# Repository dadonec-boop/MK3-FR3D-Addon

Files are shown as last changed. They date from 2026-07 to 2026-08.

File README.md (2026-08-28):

# MK3 + FR3D Addon

Public firmware for the **Desktop Filament Extruder MK3**, with **FR3D Addon** modifications by **Claudio Dadone**.

Based on **MACKEREL** (Marlin-derived filament extruder firmware by Filip Mulier / Hugh Lyman).

You can use this firmware in two ways:

1. **Standalone** — MK3S+ with FR3D Addon from the machine LCD (no Raspberry Pi gateway / web app required)
2. **Internet and/or LAN** — optional gateway + the same web app, over the internet or on local WiFi (with or without internet) ([fr3d-addon.web.app](http://fr3d-addon.web.app/))
   - **Raspberry Pi Zero 2 W** — compact totem; analog diameter sensor on MK3 pin **A3** (Hall / ARTME 3D optical)
   - **Raspberry Pi 3B** — full USB host; analog **A3** *or* **BDWidth** laser diameter sensor (USB on the Pi)
   - **Windows PC** — dedicated notebook/PC next to the extruder (`FR3DGateway.exe`)

---

## What this repository contains

| Content | Description |
|---|---|
| `MK3/` | Firmware sources (Arduino / Mega — flash this folder) |
| [`dist/MK3-FR3D-Addon.zip`](dist/MK3-FR3D-Addon.zip) | Ready-to-download ZIP of `MK3/` for Arduino IDE |
| [`docs/USER_GUIDE_...pdf`](docs/USER_GUIDE_FR3D_MK3_EN_ch1-2-3-4-5.pdf) | Standalone user guide (sensor, LCD, predictor operation) |
| [`docs/ayuda_fr3d_es_revision.docx`](docs/ayuda_fr3d_es_revision.docx) | Web app in-app help — Spanish review export (106 topics; live help at [fr3d-addon.web.app](https://fr3d-addon.web.app/)) |
| [`docs/diameter_sensor_infidel/`](docs/diameter_sensor_infidel/) | Printable Hall-effect (INFIDEL-style) diameter-sensor parts (STL) |
| [Pi Zero 2 W gateway image (Release)](https://github.com/dadonec-boop/MK3-FR3D-Addon/releases/tag/pi-gateway-v0.8) | Optional **Raspberry Pi Zero 2 W** factory image — analog A3, compact totem (binary only) |
| [Pi 3B gateway image (Release)](https://github.com/dadonec-boop/MK3-FR3D-Addon/releases/tag/pi-gateway-pi3b-v0.9) | Optional **Raspberry Pi 3B** factory image — analog A3 **or** BDWidth USB digital diameter (binary only) |
| [BDWidth sensor (PandaPi)](https://www.pandapi3d.com/product-page/bdwidth-sensor) | Optional contactless laser diameter sensor for use with **Pi 3B** gateway (USB-C to the Pi) |
| [Windows gateway (Release)](https://github.com/dadonec-boop/MK3-FR3D-Addon/releases/latest) | Optional Windows PC gateway package (`FR3DGateway-windows-x64.zip` — **exe binary only**) |
| Tag `v-mk3-original` | Stock MK3 (Mackerel base), **without** FR3D Addon |
| Tag `v-mk3-fr3d` / branch `main` | Latest **MK3 + FR3D Addon** |

This repository publishes **MK3 board firmware** (GPL-3.0) and, via **GitHub Releases**, **binary-only** gateway packages:

- Raspberry Pi Zero 2 W **factory SD image** (analog A3)
- Raspberry Pi 3B **factory SD image** (analog A3 or BDWidth USB)
- Windows **FR3DGateway.exe** package (dedicated PC/notebook next to the extruder)

**Gateway Python source, Pi program OTA source zips, and the web app source are not published** in this repository or its Releases.

---

## What FR3D Addon adds to the firmware

Compared with original MK3, this firmware includes:

- Diameter measurement — **Analog A3** (Hall / optical) with LCD **6-point** calibration (1.50…2.00 mm), or **Digital USB** (BDWidth via Pi 3B gateway)
- Diameter **predictor** with **Auto On / Off** (automatic E/T apply vs suggest-only); **Optimizar** sets P* by acting on E+T while puller stays in Auto
- Predictor parameter menus (basic + Advanced)
- Host serial temperature setpoint (`T` / `RTFP`) capped dynamically at **max(190 °C, predictor Tmax + 5)**, with heater safety headroom (see CHANGELOG)
- Compact USB host commands and CSV telemetry (on-demand `CSVQ`; internal fusion 2 s)
- Extended EEPROM layout for FR3D settings (current schema **V32**)

See [CHANGELOG.md](CHANGELOG.md) for the full list of changes versus original MK3.

---

## Standalone user guide

For MK3S+ with FR3D Addon operating from the machine LCD (**standalone** — without Raspberry Pi gateway / web app):

- [USER_GUIDE_FR3D_MK3_EN_ch1-2-3-4-5.pdf](docs/USER_GUIDE_FR3D_MK3_EN_ch1-2-3-4-5.pdf)
- [USER_GUIDE_FR3D_MK3_EN_ch1-2-3-4-5.docx](docs/USER_GUIDE_FR3D_MK3_EN_ch1-2-3-4-5.docx) (editable Word)

Covers project scope, Addon FR3D overview, diameter hardware (Hall-effect INFIDEL-style or ARTME 3D optical), **6-point** Analog A3 calibration on the LCD (1.50…2.00 mm), main-screen use, and recommended steps for automatic predictor operation.

Printable Hall parts: [`docs/diameter_sensor_infidel/`](docs/diameter_sensor_infidel/).

---

## Download ZIP (Arduino IDE)

If you only want to flash the board, download the ready-made package:

- **[MK3-FR3D-Addon.zip](dist/MK3-FR3D-Addon.zip)**

### Steps on your PC

1. Download [`dist/MK3-FR3D-Addon.zip`](dist/MK3-FR3D-Addon.zip).
2. Unzip it. You will get a folder named **`MK3`** (it must stay named `MK3`, matching `MK3.ino`).
3. Install **Arduino IDE** (or a compatible AVR Mega 2560 / RAMPS toolchain as used by MK3).
4. In Arduino IDE: **File → Open…** and open `MK3/MK3.ino`.
5. Select the correct **board** and **port**.
6. Click **Upload**.

After a first flash on an older EEPROM, the board may load hardcoded defaults (`Hardcoded Default Settings Loaded` on serial) or migrate known FR3D EEPROM versions to **V32** (a previous 3-point Hall calibration is reset; recapture six points).

### Alternative (from source tree)

Clone or browse this repository and open `MK3/MK3.ino` directly — same result as using the ZIP.

---

## Internet and/or LAN control (MK3s + FR3D Addon)

This is an **optional** path. Standalone LCD operation above does **not** require a Pi or the web app.

This firmware is **prepared** for remote and local control when used with the **MK3s + FR3D Addon** product stack:

- Choose **one** gateway host next to the MK3: **Pi Zero 2 W**, **Pi 3B**, or **Windows PC**
- The **same web app** runs over the **internet** or on the **local LAN / WiFi**, with or without an internet connection
- Operational reference: [http://fr3d-addon.web.app/](http://fr3d-addon.web.app/) (cloud) or `http://<Pi-IP>/` on the same WiFi (LAN)

The web app / host stack is an **additional product feature** and is **not** published here as open-source.

Prebuilt **SD images** for both Pi gateways are available under [Releases](https://github.com/dadonec-boop/MK3-FR3D-Addon/releases) (image files only).

### Which Raspberry Pi should I use?

| Gateway | Best for | Diameter sensor |
|---|---|---|
| **Pi Zero 2 W** | Smallest totem on the extruder | Analog **A3** only (Hall INFIDEL or ARTME 3D optical on the MK3) |
| **Pi 3B** | BDWidth digital diameter or analog A3 with full USB ports | Analog **A3** *or* **[BDWidth](https://www.pandapi3d.com/product-page/bdwidth-sensor)** laser sensor (USB-C on the Pi) |
| **Windows PC** | Reuse an existing PC | Analog **A3** (sensor wired to the MK3 Mega) |

**BDWidth** is an optical width/motion sensor (PandaPi). Purchase: [pandapi3d.com — bdwidth sensor](https://www.pandapi3d.com/product-page/bdwidth-sensor).  
It connects to a **Pi 3B USB port** (USB-C cable included). The Pi Zero 2 W has **no USB host** for an extra sensor — use Pi 3B for BDWidth.

On Pi 3B with both devices connected, **any two USB-A ports** work. The gateway identifies the MK3 serial link (250000 baud, saved in config) and auto-detects BDWidth (500000 baud, PandaPi `pandapi3dV` probe) — you do not assign a fixed physical port number.

---

## Download Raspberry Pi Zero 2 W gateway image

Recommended when you use an **analog diameter sensor on MK3 pin A3** and want the smallest gateway totem.

Download the factory image from the Release:

- **[fr3daddon-v0.8-small.img.zst](https://github.com/dadonec-boop/MK3-FR3D-Addon/releases/download/pi-gateway-v0.8/fr3daddon-v0.8-small.img.zst)**  
  Release notes: [pi-gateway-v0.8](https://github.com/dadonec-boop/MK3-FR3D-Addon/releases/tag/pi-gateway-v0.8)

**Wiring (summary):** micro SD, **+5 V 2 A** on **PWR_IN**, **USB OTG** data port → MK3S+ USB-B (printer port).

After first boot, update the gateway program with CONSOLE `PI UPDATE GATEWAY latest`. That does **not** replace the SD image.

### Flash with Raspberry Pi Imager

1. Download [Raspberry Pi Imager](https://www.raspberrypi.com/software/).
2. Insert a micro SD card (**32 GB** or larger recommended).
3. Open Imager → **Choose OS** → **Use custom** → select `fr3daddon-v0.8-small.img.zst`.
4. **Choose storage** → your SD card → **Write**.
5. Insert the SD into the Pi Zero 2 W and power on.

---

## Download Raspberry Pi 3B gateway image (+ BDWidth)

Recommended when you use the **[BDWidth](https://www.pandapi3d.com/product-page/bdwidth-sensor)** contactless laser diameter sensor, or when you want analog A3 with a full-size Pi and multiple USB ports.

Download the factory image from the Release:

- **[fr3daddon-pi3b-v0.9-small.img.zst](https://github.com/dadonec-boop/MK3-FR3D-Addon/releases/download/pi-gateway-pi3b-v0.9/fr3daddon-pi3b-v0.9-small.img.zst)**  
  Release notes: [pi-gateway-pi3b-v0.9](https://github.com/dadonec-boop/MK3-FR3D-Addon/releases/tag/pi-gateway-pi3b-v0.9)

**Wiring (summary):**

- micro SD + **+5 V** power (micro USB)
- **MK3S+ USB-B** → any Pi 3B **USB-A** port (FR3D serial link to the Mega)
- **BDWidth USB-C** → another Pi 3B **USB-A** port (digital diameter; gateway auto-detects the sensor)
- On the MK3 LCD set **Diameter Sensor → Source → Digital USB** when using BDWidth

After first boot, update the gateway program with CONSOLE `PI UPDATE GATEWAY latest`. That does **not** replace the SD image.

### Flash with Raspberry Pi Imager

Same steps as Pi Zero 2 W, but select `fr3daddon-pi3b-v0.9-small.img.zst` and boot on a **Raspberry Pi 3B**.

---

## First boot / factory defaults (Pi Zero 2 W and Pi 3B)

- WiFi hotspot: **SSID `addonfr3d`** / password **`addonfr3d`**
- On the MK3S+ LCD open **Control → gateway FR3D**. That screen shows the web app URL, WiFi SSID, the gateway **IP** (with online status), and the pairing **Token**:

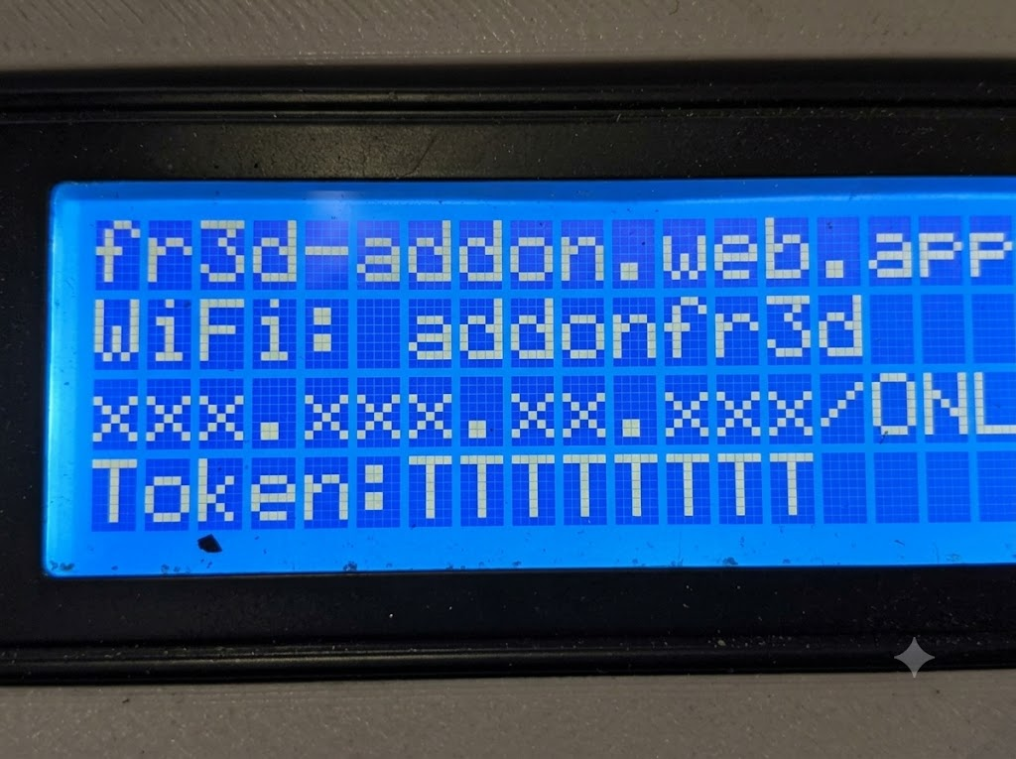
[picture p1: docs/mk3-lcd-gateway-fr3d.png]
MK3S+ LCD — gateway FR3D (IP and Token)
  

- Local setup page (from a device on the same WiFi / hotspot): **`http://<IP_from_LCD>:8080/`**  
  Use the IP shown on line 3 of the LCD (before `/ONL` or `/OFF`).  
  Login: **`addonfr3d` / `addonfr3d`**
- On first boot the image personalizes hostname / SSH keys automatically (no manual script needed).
- Then continue pairing from the web app ([fr3d-addon.web.app](http://fr3d-addon.web.app/)) using the **Token** from the same LCD screen.

---

## License

- **Firmware in this repository (`MK3/`):** [GPL-3.0](LICENSE)
  - Upstream Mackerel/Marlin base remains free software under the GNU GPL
  - FR3D Addon modifications are distributed under the same GPL-3.0 terms

- **Internet control stack (web app + gateway source):**  
  **not** included in this repository and **not** licensed here as public open-source software.

- **Pi Zero 2 W and Pi 3B factory images (Release assets):** distributed as binary images for end users; gateway source code is not published in this repository.

---

## Links

- Firmware ZIP (Arduino IDE): [dist/MK3-FR3D-Addon.zip](dist/MK3-FR3D-Addon.zip)
- Standalone user guide (PDF): [docs/USER_GUIDE_FR3D_MK3_EN_ch1-2-3-4-5.pdf](docs/USER_GUIDE_FR3D_MK3_EN_ch1-2-3-4-5.pdf)
- Pi Zero 2 W gateway image: [fr3daddon-v0.8-small.img.zst](https://github.com/dadonec-boop/MK3-FR3D-Addon/releases/download/pi-gateway-v0.8/fr3daddon-v0.8-small.img.zst)
- Pi 3B gateway image: [fr3daddon-pi3b-v0.9-small.img.zst](https://github.com/dadonec-boop/MK3-FR3D-Addon/releases/download/pi-gateway-pi3b-v0.9/fr3daddon-pi3b-v0.9-small.img.zst)
- BDWidth sensor (purchase): [pandapi3d.com — bdwidth](https://www.pandapi3d.com/product-page/bdwidth-sensor)
- Gateway program (Pi OTA + Windows): [latest Release](https://github.com/dadonec-boop/MK3-FR3D-Addon/releases/latest)
- System / web app reference: [http://fr3d-addon.web.app/](http://fr3d-addon.web.app/)
- Source: [github.com/dadonec-boop/MK3-FR3D-Addon](https://github.com/dadonec-boop/MK3-FR3D-Addon)

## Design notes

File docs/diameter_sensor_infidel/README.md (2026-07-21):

# Diameter sensor — Hall-effect (INFIDEL style) printed parts

## File

| File | Description |
|---|---|
| [`Hall_Sensor_Parts.stl`](Hall_Sensor_Parts.stl) | Single STL containing **all 9** printable bodies |

## How to print

1. Open `Hall_Sensor_Parts.stl` in your slicer (PrusaSlicer, Bambu Studio, Cura, Orca, etc.).
2. **Split into individual parts** (the file is a multi-body / multi-object mesh):
   - PrusaSlicer / Orca: right-click object → **Split** → **To objects** (or *To parts*).
   - Bambu Studio: right-click → **Split into objects**.
   - Cura: **Mesh Tools** → **Split model into parts** (plugin) or import and separate.
3. Arrange each piece on the bed and print (PLA/PETG as preferred for the head).
4. Assemble with roller, magnet, and SS495A linear Hall-effect sensor; mount on the MK3S+ filament path.

## Reference

- INFIDEL design (Printables): https://www.printables.com/model/57154-infidel-inline-filament-diameter-estimator-lowcost
- Standalone user guide: [`USER_GUIDE_FR3D_MK3_EN_ch1-2-3-4-5.pdf`](../USER_GUIDE_FR3D_MK3_EN_ch1-2-3-4-5.pdf)
- Web app help: [fr3d-addon.web.app](http://fr3d-addon.web.app/) → Hardware → Diameter Sensor Hardware

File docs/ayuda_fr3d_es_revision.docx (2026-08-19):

# FR3D — Ayuda in-app (español) para revisión

Instrucciones: edite solo Título, Resumen y Cuerpo. No cambie las líneas ID / Padre. Al terminar, en Google Docs: Archivo → Descargar → Microsoft Word (.docx) y envíelo. El recargo traducirá inglés y alemán a partir de este español.

Temas: 106. Idioma de este archivo: español solamente.

# FR3dAddon

ID: help.fr3d-addon [sección]

Título

FR3dAddon

Resumen (una línea)

FR3dAddon - Un producto de Formake3D compuesto de Firmware, Software y Hardware que extiende las funcionalidades del extrusor de filamento MK3S+ de ARTME3D.

Cuerpo

FR3dAddon permite, entre otras funciones, el control predictivo de diámetro del filamento y la optimización del rendimiento del flujo de material por minuto.

FR3dAddon incorpora la medición de diámetro. Ofrece tres posibilidades:
- Control de diámetro manual
- Control de diámetro analógico por el pin A3 de la placa MEGA del MK3S+
- Control de diámetro digital por puerto USB de la placa MEGA del MK3S+ a través del gateway de hardware FR3dAddon

=== Guía rápida — tres formas de operar ===

Elija un camino. Quien instala por primera vez suele mezclarlos.

> Nota de Arquitectura del Sistema:
> Cabe destacar que en la arquitectura de FR3dAddon, el firmware MK3S+FR3dAddon mantiene el control del lazo de realimentación (a través del sensor y el predictor), lo cual es fundamental para la estabilidad; mientras que el gateway (Pi o Windows) se encarga de la capa superior de monitoreo, análisis y comandos de alta complejidad. Esto evita que la latencia de LAN/Internet rompa el proceso crítico de control de extrusión.

1) Standalone — solo LCD de taller
Operación exclusiva en taller: Smart LCD y encoder del MK3S+. Sin gateway y sin app web.
- Descargar y aplicar el firmware MK3S+FR3dAddon desde GitHub FR3dAddon.
- Sensor analógico A3 o diámetro Manual (el Digital USB necesita gateway).
- Más: vea A) Standalone MK3S.

2) LAN — WiFi local, sin internet
La app web habla con el gateway (Raspberry Pi o PC Windows) en la misma WiFi del taller.
- El mismo firmware MK3 y UN gateway (imagen Pi o zip Windows).
- Pi: lea la IP en LCD Control -> AddonFR3D / Gateway FR3D (tercera línea) y abra http://xxx.xxx.xxx.xxx/
- Windows: ejecute FR3DGateway.exe en el PC junto a la máquina, misma WiFi.
- Más: vea B) Mk3s+Fr3dAddon ONLINE.

3) FULL Cloud — remoto por internet
Firebase + gateway junto a la máquina + https://fr3d-addon.web.app/
- El mismo gateway que LAN. Primera vez: cree usuario y contraseña, y asigne el token de 8 caracteres del LCD (misma pantalla, cuarta línea).
- Más: vea B) Mk3s+Fr3dAddon ONLINE.

Decisión
- ¿Solo LCD en la máquina? -> Standalone.
- ¿Misma WiFi, sin internet? -> LAN.
- ¿Control desde otro sitio o desde casa? -> FULL Cloud.

Si eligió LAN o FULL Cloud (Pi): Raspberry Pi Zero 2 W, microSD de 32 GB o más, grabe la imagen de fábrica, cable USB/OTG al MK3. WiFi primera vez: comparta internet del teléfono. SSID addonfr3d, contraseña addonfr3d. Después puede definir la WiFi del sitio.

Una vez dentro de la app podrá:
- Configuraciones en la pestaña Config
- Extruir filamento en Extrusor
- Bobinar filamento en Bobinador
- Analizar la traza de un filamento procesado en Análisis
- Ver y ejecutar comandos de control y estado en Consola
Más información de este modo: vea B) Mk3s+Fr3dAddon ONLINE.

Nota: descargas y GitHub - vea Recursos GitHub FR3dAddon.

Común a ambos modos: hardware del sensor de diámetro (vea Hardware - sensor).

Ver también (no editar): help.fr3d-addon.github, help.fr3d-addon.download, help.mk3, help.global, help.hardware, help.tips, help.tips.predictor-codes, help.global.help-panel

## Recursos GitHub FR3dAddon

ID: help.fr3d-addon.github Padre: help.fr3d-addon

Título

Recursos GitHub FR3dAddon

Resumen (una línea)

Descargas públicas: repo, zip MK3, PDF guía, STL, imagen Pi, gateway Windows.

Cuerpo

Acceda al repositorio GitHub FR3dAddon para:

Repositorio completo en GitHub:
https://github.com/dadonec-boop/MK3-FR3D-Addon

Paquete de firmware MK3 (instalar con Subir en Arduino IDE):
https://github.com/dadonec-boop/MK3-FR3D-Addon/raw/main/dist/MK3-FR3D-Addon.zip

Guía de usuario standalone (sensor, LCD, predictor) — PDF:
https://github.com/dadonec-boop/MK3-FR3D-Addon/raw/main/docs/USER_GUIDE_FR3D_MK3_EN_ch1-2-3-4-5.pdf

Piezas imprimibles sensor Hall (estilo INFIDEL) — carpeta STL:
https://github.com/dadonec-boop/MK3-FR3D-Addon/tree/main/docs/diameter_sensor_infidel
Archivo STL multi-cuerpo:
https://github.com/dadonec-boop/MK3-FR3D-Addon/raw/main/docs/diameter_sensor_infidel/Hall_Sensor_Parts.stl

Imagen de fábrica Raspberry Pi Zero 2 W (solo binario):
https://github.com/dadonec-boop/MK3-FR3D-Addon/releases/download/pi-gateway-v0.8/fr3daddon-v0.8-small.img.zst
Página del release: https://github.com/dadonec-boop/MK3-FR3D-Addon/releases/tag/pi-gateway-v0.8

Paquete gateway PC Windows — solo exe:
https://github.com/dadonec-boop/MK3-FR3D-Addon/releases/latest/download/FR3DGateway-windows-x64.zip
Todos los releases: https://github.com/dadonec-boop/MK3-FR3D-Addon/releases

Ver también (no editar): help.fr3d-addon.download, help.mk3.firmware, help.hardware, help.config.windows-gateway

## A) Standalone MK3S

ID: help.mk3 Padre: help.fr3d-addon [sección]

Título

A) Standalone MK3S

Resumen (una línea)

—

Cuerpo

A) Standalone MK3S - Opere el MK3S+ solo desde su Smart LCD: instale el firmware addon FR3D, lea el diámetro en la pantalla principal, configure menús AddonFR3D y calibre el sensor. No hace falta gateway ni app web para producir en local. Pros: más simple; offline; enfoque de taller. Contras: sin UI remota, roles en la nube ni análisis CSV web. Cableado del sensor en Hardware (común a A y B). Para control nube/web vea B) Mk3s+Fr3dAddon ONLINE.

Ver también (no editar): help.mk3.overview, help.mk3.firmware, help.hardware, help.global

### Cómo funciona standalone

ID: help.mk3.overview Padre: help.mk3

Título

Cómo funciona standalone

Resumen (una línea)

Producir solo desde el LCD del MK3: diámetro, menús AddonFR3D, sin internet.

Cuerpo

Cómo funciona standalone - Use solo el LCD y el encoder rotativo de la impresora. Vea diámetro en vivo (DXXXX/YYYY), modo predictor (A/M) y calibre el sensor desde Menú -> AddonFR3D / Control. No hace falta internet, Firebase ni login web para extruir.

Camino típico - Instale el firmware FR3D, cablee el sensor (Hardware) y produzca desde el LCD.

Después puede agregar un gateway y seguir usando el LCD a la vez; ese camino nube/colaborativo está en B) Mk3s+Fr3dAddon ONLINE (sin duplicar aquí). La calibración web (CONFIG) también vive en ONLINE.

Ver también (no editar): help.mk3.firmware, help.mk3.main-screen, help.mk3.hall-lcd-calibration, help.hardware, help.global

### Firmware MK3s+FR3D Addon GW

ID: help.mk3.firmware Padre: help.mk3

Título

Firmware MK3s+FR3D Addon GW

Resumen (una línea)

Cargar firmware FR3D en el MK3S+ para menús LCD, sensor Ø y gateway.

Cuerpo

Firmware MK3s+FR3D Addon GW - La placa principal de la impresora necesita el firmware addon FR3D para menús AddonFR3D en el LCD, sensor de diámetro y enlace USB al gateway (Pi o Windows).

Cómo instalarlo (montaje)
1) Conecte un PC Windows al USB-B del MK3S+ (cable de la impresora, no el del gateway).
2) Descargue el paquete MK3 y extráigalo en una carpeta vacía:
https://github.com/dadonec-boop/MK3-FR3D-Addon/raw/main/dist/MK3-FR3D-Addon.zip
3) Abra Arduino IDE y abra el proyecto de la subcarpeta MK3.
4) Elija placa Makerbase MKS Gen_L V2.1 y el puerto USB de la impresora (Herramientas -> Puerto).
5) Pulse Subir y espere a que termine (no desconecte el USB).

Luego reinicie la impresora si hace falta. Para control nube/LAN, conecte el Gateway FR3D Addon por USB. Solo taller: use los menús del LCD (standalone).

Ver también (no editar): help.config.hall.hardware, help.global.gateway, help.config.wifi.first-setup, help.mk3.overview

### Pantalla principal (display de diámetro)

ID: help.mk3.main-screen Padre: help.mk3

Título

Pantalla principal (display de diámetro)

Resumen (una línea)

DXXXX/YYYY en fila 2; A = predictor auto, M = manual.

Cuerpo

Pantalla principal - En el LCD home del MK3S+, la segunda fila muestra diámetro de filamento y modo predictor.

Campos de pantalla
1) DXXXX - Diámetro actual (XXXX = valor x 1000, ej. 1745 -> 1,745 mm)
2) /YYYY - Promedio de los últimos 10 s (20 muestras), ej. /1755 -> 1,755 mm
3) A o M - Modo predictor al final: A = ajuste automático, M = manual

Con Auto ON, el LCD puede mostrar tokens de estado junto a A (AH, AB, AS, AC, AO, AG, AN, AP, AU, AZ, AE±, AT±). Imprima la tabla de taller en Consejos y trucos → Códigos LCD del predictor. Los mismos códigos aparecen en el panel Flutter y en Ayuda → Extrusor → Asistente predictivo.

Use esta fila para verificar calibración del sensor de diámetro y compensación OFFSET sin abrir la app web.

Ver también (no editar): help.mk3.hall-lcd-calibration, help.extruder.live-status, help.tips.predictor-codes

### Calibración Diameter Sensor (menú MK3)

ID: help.mk3.hall-lcd-calibration Padre: help.mk3

Título

Calibración Diameter Sensor (menú MK3)

Resumen (una línea)

Source A3/USB/Manual, 6-pt 1.5-2.0, Need Calibrate! / CALIBRATE, OFFSET.

Cuerpo

Diameter Sensor en LCD MK3 - Menú -> Control -> AddonFR3D -> Diameter Sensor.

Source (exclusivo) - Analógico A3 (Hall/óptico en A3), Digital USB (BDWidth por el gateway) o Manual (editar D mm en LCD; el Ø no caduca). Solo una fuente activa. Firmware antiguo puede mostrar solo Analógico A3 (sin submenú Source); actualice el MK3 para USB/Manual.

Firmware actual - Línea 6-pt 1.5-2.0 (sin Pattern A/B). Capture seis patrones físicos: 1.50, 1.60, 1.70, 1.80, 1.90, 2.00 mm. Click guarda ADC. CALV=1 solo si los seis ADC son distintos y monótonos. Flashear este firmware borra una cal Hall de 3 puntos previa (EEPROM V32).

Firmware antiguo - Pattern Diameter muestra Now (p. ej. 1.7/1.75/2.0) y Set del otro preset (1.5/1.7/2.0 o 1.7/1.75/2.0). Cambiar patrón borra los 3 puntos y pone OFFSET (DOFF) en 0. La app web mantiene la UI A/B hasta reflashear el Mega.

Need Calibrate! - Solo si la calibración está incompleta (CALV=0). Click abre la lista Capture. Si ya está calibrado (CALV=1), el menú muestra CALIBRATE.

CALIBRATE - Capture cada mm etiquetado con el patrón físico correspondiente (Click guarda ADC).

OFFSET - Compensación fina de diámetro (DOFF). El predictor no actúa hasta CALV=1.
Mismos valores EEPROM que CONFIG -> Calibración sensor de diámetro (web).

Si Need Calibrate! no desaparece, el Ø queda congelado o el LCD muestra AC: vea Consejos → Calibración del sensor: solución de problemas (voltaje A3, limpiar Hall/óptico, comprobar que DXXXX se mueve).

Ver también (no editar): help.config.hall, help.config.hall.hardware, help.mk3.main-screen, help.tips.sensor-calibrate

## B) Mk3s+Fr3dAddon ONLINE LAN y/o INTERNET

ID: help.global Padre: help.fr3d-addon [sección]

Título

B) Mk3s+Fr3dAddon ONLINE LAN y/o INTERNET

Resumen (una línea)

—

Cuerpo

B) Mk3s+Fr3dAddon ONLINE - Operación en la red LAN y/o internet: app web Flutter + Firebase + host gateway (Raspberry Pi Zero 2 W o PC Windows).
Primera vez:
descargue UN paquete de gateway, flashee/ejecute, luego empareje el token del LCD. Esta rama cubre la UI web, software/hardware del gateway (Pi o Windows), pestañas y consola. Para producción solo LCD vea A) Standalone MK3S. Cableado del sensor en Hardware (común).

Ver también (no editar): help.fr3d-addon.download, help.fr3d-addon.cloud, help.global.tabs, help.mk3, help.hardware

### Resumen

ID: help.global.overview Padre: help.global

Título

Resumen

Resumen (una línea)

Control remoto del MK3S+ vía gateway FR3D en LAN o INTERNET.

Cuerpo

Resumen - Esta aplicación web controla un extrusor de filamento MK3S+ a través de un gateway FR3D en la nube (tótem Raspberry Pi Zero o un PC/notebook Windows dedicado junto a la máquina).
Comandos y telemetría viajan por Firebase Realtime Database.
Use la pestaña
EXTRUSOR para producción y predictor,
BOBINADOR para bobinado,
ANÁLISIS para logs CSV,
CONFIG para gateway y sensores,
CONSOLA (admin/super) para comandos en bruto.
Vea Cabecera de la app (zonas 1 y 2) para barra de estado y controles.

Ver también (no editar): help.fr3d-addon.download, help.global.header, help.global.gateway, help.global.tabs, help.config.windows-gateway

### Nube: descargar gateway (primera vez)

ID: help.fr3d-addon.download Padre: help.global

Título

Nube: descargar gateway (primera vez)

Resumen (una línea)

La nube necesita UN host: zip Windows O imagen Pi Zero 2 W. Enlaces aquí.

Cuerpo

Nube: descargar gateway (primera vez) - Si va a operar ONLINE, lo primero es un gateway junto al MK3. Elija UNA opción y descárguela.

No descargue ambos para una sola máquina. Elija PC Windows o Raspberry Pi Zero 2 W.

=== A) PC / notebook Windows (USB al MK3) ===
Archivo: FR3DGateway-windows-x64.zip
Descarga:
https://github.com/dadonec-boop/MK3-FR3D-Addon/releases/latest/download/FR3DGateway-windows-x64.zip
Todos los releases: https://github.com/dadonec-boop/MK3-FR3D-Addon/releases
Luego: descomprima, ejecute Iniciar_FR3DGateway.bat o FR3DGateway.exe, conecte USB, empareje el token en la app web.
Detalle: Gateway en PC Windows (CONFIG).

=== B) Raspberry Pi Zero 2 W (imagen SD de fábrica) ===
Archivo: fr3daddon-v0.8-small.img.zst (flashear a microSD)
Descarga:
https://github.com/dadonec-boop/MK3-FR3D-Addon/releases/download/pi-gateway-v0.8/fr3daddon-v0.8-small.img.zst
Página del release: https://github.com/dadonec-boop/MK3-FR3D-Addon/releases/tag/pi-gateway-v0.8
Luego: flashee la imagen, cablee alimentación/USB (vea Raspberry Pi GW hardware y software), únase al hotspot addonfr3d, dé internet a la Pi, empareje el token.

Cuando el gateway esté online - Abra https://fr3d-addon.web.app/ , inicie sesión e ingrese el token de 8 caracteres del LCD del MK3 (Control -> addonfr3d-gateway).

Updates posteriores - Pi: PI UPDATE en CONSOLA. Windows: WINDOWS UPDATE CHECK / HOWTO (no es una nueva imagen SD). Vea Actualizar gateway.

Ver también (no editar): help.fr3d-addon.cloud, help.fr3d-addon.modes, help.config.windows-gateway, help.config.wifi.first-setup, help.config.gateway.hardware, help.config.gateway.ota

### Hosts ONLINE: Pi vs Windows

ID: help.fr3d-addon.modes Padre: help.global

Título

Hosts ONLINE: Pi vs Windows

Resumen (una línea)

Misma app en la nube; elija tótem Pi Zero 2 W o gateway PC Windows.

Cuerpo

Hosts ONLINE: Pi vs Windows - Ambos usan la misma app web online. Elija el host gateway que convenga al taller.

1) Nube + Raspberry Pi Zero 2 W
Tótem compacto en la extrusora, USB/serial al MK3, internet por WiFi. PRIMERA DESCARGA: imagen SD de fábrica (Nube: descargar gateway).
Pros: siempre encendido; poco espacio; imagen con hotspot; control remoto; updates remotos; app de control local opcional en LAN (http://<IP-Pi>/) mientras Firebase sigue andando.
Contras: hardware Pi + imagen SD; WiFi del sitio; la UI en la nube depende de Firebase/internet (la UI LAN no).

2) Nube + gateway PC Windows
PC/notebook Windows dedicado junto a la extrusora con FR3DGateway.exe (USB COM).
PRIMERA DESCARGA: FR3DGateway-windows-x64.zip (Nube: descargar gateway).
Pros: aprovecha un PC habitual; COM fácil en CONFIG; updates por zip (WINDOWS UPDATE CHECK/HOWTO).
Contras: el PC debe quedar encendido y online; menos compacto; unzip manual; Firebase para la web.

Ver también (no editar): help.fr3d-addon.download, help.fr3d-addon.cloud, help.config.windows-gateway, help.config.gateway.hardware, help.config.wifi.first-setup, help.mk3

### Control Internet y/o LAN

ID: help.fr3d-addon.cloud Padre: help.global

Título

Control Internet y/o LAN

Resumen (una línea)

Misma app por internet o en LAN (WiFi), con o sin conexión a internet. Primero: descargar UN gateway.

Cuerpo

Control Internet y/o LAN - Además de usarla por internet, también puede operar la máquina en la red local (LAN) por WiFi, con o sin conexión a internet. Es la misma app: tanto en local como desde internet.

Para operar la máquina desde el navegador necesita:

1) La app web en https://fr3d-addon.web.app/ - inicie sesión, empareje con el token del LCD y use EXTRUSOR / BOBINADOR / ANÁLISIS / CONFIG / CONSOLA.
2) Un gateway junto al MK3 (elija uno):
- Raspberry Pi Zero 2 W con la imagen SD de fábrica, o
- un PC Windows con FR3DGateway (USB a la impresora).

PRIMERA VEZ - Descargue exactamente un gateway antes de emparejar:
- Windows: https://github.com/dadonec-boop/MK3-FR3D-Addon/releases/latest/download/FR3DGateway-windows-x64.zip
- Imagen Pi: https://github.com/dadonec-boop/MK3-FR3D-Addon/releases/download/pi-gateway-v0.8/fr3daddon-v0.8-small.img.zst
Vea también: Nube: descargar gateway (primera vez).

LAN en Pi - En la misma WiFi puede abrir http://<IP-Pi>/ (sin login), aunque no haya internet. Nube y LAN llegan a la misma Pi; use una sesión a la vez. Vea Ayuda -> Config -> App LAN y setup.

Ver también (no editar): help.fr3d-addon.download, help.fr3d-addon.modes, help.config.gateway.hardware, help.config.windows-gateway, help.global.tabs

### Emparejamiento del gateway

ID: help.global.gateway Padre: help.global

Título

Emparejamiento del gateway

Resumen (una línea)

Seleccione nombre y token del gateway para conectar esta sesión.

Cuerpo

Emparejamiento - Cada tótem físico (host Pi o PC Windows) tiene una clave de gateway y un token de 8 caracteres. Pulse el nombre o token en la barra de estado (zona 1) para abrir el selector y cambiar de tótem. Todos los comandos POLL3 y manuales van solo al gateway emparejado. Si el gateway o la nube Firebase están fuera de línea (punto de enlace rojo o gris), la app bloquea todos los comandos y deshabilita Extrusor, Bobinador, Predictor y Consola hasta que el gateway vuelva a estar en línea - así la UI no simula cambios que la máquina no recibió.

Ver también (no editar): help.global.user, help.global.header, help.global.connection, help.config.windows-gateway

### Usuario

ID: help.global.user Padre: help.global [sección]

Título

Usuario

Resumen (una línea)

—

Cuerpo

Inicio de sesión, roles y selección de tótem para operadores y superusuarios.

### Iniciar sesión (Operador)

ID: help.tips.operator-login Padre: help.global.user

Título

Iniciar sesión (Operador)

Resumen (una línea)

Correo y contraseña; el primer acceso pide el token del Gateway MK3S+.

Cuerpo

Iniciar sesión - Abra la app web e ingrese correo y contraseña. Si es su primera visita, pulse "Primera vez - crear cuenta", elija contraseña y regístrese. Use "Olvidé mi contraseña" si necesita un enlace por correo.

Primer emparejamiento - La primera vez que inicia sesión con una cuenta nueva (o sin tótem guardado), la app abre la pantalla de emparejamiento y pide el TOKEN mostrado en el MK3S+ en el menú Gateway. Este código de 8 caracteres lo asigna el Gateway FR3D Addon en la Raspberry Pi Zero 2 W conectada a la máquina. Escríbalo exactamente, opcionalmente un nombre amigable, y conecte. El tótem queda guardado en su cuenta.

Perfil operador - Tras iniciar sesión y emparejar puede usar EXTRUSOR, BOBINADOR, ANÁLISIS, CONFIG y CONSOLA. En la consola solo hay botones rápidos (CONECTAR, DESCONECTAR, WIFI, WHOAREYOU): sin texto libre ni ayuda de consola. En las demás pestañas puede ejecutar comandos de producción, pero no SO ni PI a nivel de host. Guardar perfiles del predictor globalmente en Firebase es para superusuarios; los operadores pueden cargar perfiles y ajustar parámetros en la sesión actual.

Configuración inicial de la Pi - Para una Raspberry Pi Zero 2 W nueva (imagen de fábrica, hotspot addonfr3d, token del menú MK3S+) vea CONFIG -> WiFi -> Configuración inicial del gateway en Ayuda. En la misma LAN puede abrir http://<IP-Pi>/ (app de control, sin login).

Ver también (no editar): help.global.roles, help.tips.operator-totem, help.config.wifi.first-setup, help.config.setup-web

### Roles de usuario

ID: help.global.roles Padre: help.global.user

Título

Roles de usuario

Resumen (una línea)

Operadores vs superusuarios; algunas acciones están restringidas.

Cuerpo

Roles - Los operadores pueden usar controles de producción dentro de los límites de su perfil. Los superusuarios pueden acceder a la CONSOLA, guardar perfiles del predictor globalmente en Firebase y gestionar usuarios. Si un botón está deshabilitado, su rol o el estado de la máquina puede bloquear la acción (por ejemplo, extrusor en marcha bloquea inicio del bobinador).

Ver también (no editar): help.tips.operator-login, help.console

### Tótem Gateway (Operador)

ID: help.tips.operator-totem Padre: help.global.user

Título

Tótem Gateway (Operador)

Resumen (una línea)

Elija el tótem de la máquina en la barra de estado; token de 8 caracteres.

Cuerpo

Selección de tótem - Cada línea de extrusión tiene un gateway Raspberry Pi (tótem) identificado por un token de 8 caracteres. En la barra gris bajo la cabecera, pulse el nombre o token subrayado para abrir el selector de gateway.

Tótems guardados - Seleccione uno de la lista. Puede asignar un nombre amigable al emparejar un token nuevo para reconocerlo fácilmente en planta.

Entrada manual - Ingrese el token de 8 caracteres del menú Gateway del MK3S+ (Gateway FR3D Addon en Raspberry Pi Zero 2 W), opcionalmente un nombre, y conecte.

Cambio - Cambiar de tótem no cierra la sesión. Todos los comandos y el estado en vivo aplican solo al gateway emparejado actual. Confirme el punto verde antes de iniciar extrusión o bobinado. Si el gateway o la nube están fuera de línea (punto rojo o gris), los comandos se bloquean y los controles de máquina quedan deshabilitados hasta que la Pi vuelva a estar en línea.

Ver también (no editar): help.global.gateway, help.global.connection

### Cabecera de la app (zonas 1 y 2)

ID: help.global.header Padre: help.global [sección]

Título

Cabecera de la app (zonas 1 y 2)

Resumen (una línea)

Zona 1 = barra de estado; zona 2 = sesión y vista.

Cuerpo

Cabecera de la app - La parte superior de la pantalla tiene dos zonas operativas:

1 - Barra de estado (conexión)
Franja gris bajo la marca y las pestañas. Muestra el color del enlace, la etiqueta de máquina, el token de 8 caracteres, la cuenta regresiva del poll y actualizar. Use esta zona para ver si la Pi está en línea y para cambiar de tótem.

2 - Controles de sesión y vista
Botones arriba a la derecha: CERRAR SESIÃ"N, ACERCA DE, idioma (EN/ES/DE), Ayuda (?) y zoom (+/- %). Controlan la sesión del navegador y el diseño de la página; no arrancan la extrusión.

Expanda los subtemas abajo para el detalle de cada zona.

Ver también (no editar): help.global.connection, help.global.header-actions, help.global.tabs

### 1 - Barra de estado (conexión)

ID: help.global.connection Padre: help.global.header

Título

1 - Barra de estado (conexión)

Resumen (una línea)

Color del enlace, etiqueta, token, cuenta regresiva del poll y actualizar.

Cuerpo

1 - Barra de estado (conexión)

Es la franja gris bajo EXTRUSOR / BOBINADOR / ANÁLISIS / CONFIG (zona 1 de la cabecera). De izquierda a derecha:
- Etiqueta de enlace en color - Estado combinado Firebase + gateway Pi + MK3 (por ejemplo verde MK3S conectado, naranja Gateway FUERA DE LÍNEA, gris problemas de nube).
- Etiqueta de máquina (p. ej. IZQ) - Subrayada; pulse para abrir el selector de gateway / tótem.
- Token (8 caracteres, p. ej. NWS7QRVY) - Subrayado; mismo selector que la etiqueta.
- Cuenta regresiva del poll - Barra segmentada / reloj hasta el próximo POLL2 automático.
- Icono actualizar - Sonda de inmediato y sale del standby.

Si esta zona dice Gateway FUERA DE LÍNEA, la Pi no responde. El standby reduce el poll; pulse actualizar cuando la Pi vuelva.

Ver también (no editar): help.global.header, help.global.polling, help.global.gateway

### Poll y standby

ID: help.global.polling Padre: help.global.connection

Título

Poll y standby

Resumen (una línea)

Telemetría automática cada 10-15 s; standby en reposo, frío u offline.

Cuerpo

Poll y standby - Durante el trabajo, la app consulta el gateway cada 10-15 segundos (más rápido con extrusión o bobinador activo). Si nada está en marcha, la temperatura real está bajo 100 degC y el objetivo no supera 150 degC (no hay preparación de corrida), entra en standby y consulta cada 30 minutos para ahorrar ancho de banda. Si el gateway Pi está offline (o cae el enlace Firebase) y no hay sesión de extrusión/bobinador, también entra en standby para no spamear polls fallidos. Cualquier pulsación o actualización manual reinicia la actividad y vuelve al poll normal. PAUSA del bobinador se trata como sesión activa y no debe entrar en standby.

Ver también (no editar): help.global.connection

### 2 - Controles de sesión y vista

ID: help.global.header-actions Padre: help.global.header

Título

2 - Controles de sesión y vista

Resumen (una línea)

Cerrar sesión, Acerca de, idioma, Ayuda y zoom.

Cuerpo

2 - Controles de sesión y vista

Arriba a la derecha de la cabecera blanca (zona 2), de izquierda a derecha:
- CERRAR SESIÃ"N - Termina el login Firebase en este navegador.
- ACERCA DE - Versión de la app, build id, créditos y QR al sitio del producto.
- Idioma (globo + EN/ES/DE) - Idioma de la UI y de este panel de ayuda.
- Ayuda (?) - Abre este árbol de ayuda (por defecto: FR3dAddon).
- Zoom - / % / + - Escala toda la UI por igual en ancho y alto (mantiene proporción). También Ctrl + rueda. Clic en el % para volver a 100%.

Estos controles nunca envían comandos EXTRUSOR ni BOBINADOR; solo afectan la sesión y el diseño.

Ver también (no editar): help.global.header, help.global.help-panel, help.global.tabs

### Pestañas

ID: help.global.tabs Padre: help.global [sección]

Título

Pestañas

Resumen (una línea)

EXTRUSOR, BOBINADOR, ANÁLISIS, CONFIG y CONSOLA (superusuario).

Cuerpo

EXTRUSOR - Extrusión en vivo, predictor, material, alertas de diámetro y gráficos.
BOBINADOR - Velocidad de bobinado, objetivo de metros, límites, inicio/parada/pausa y offset.
ANÁLISIS - Cargar logs CSV de materiales desde la Pi y revisar historial offline.
CONFIG - Detalles del gateway, calibración del sensor de diámetro y ajustes relacionados.
CONSOLA - Línea de comandos en bruto (solo superusuario).

Expande cada pestaña abajo para temas detallados.
Desde la app principal, use los chips Acceso directo a pestañas para ir a una pestaña.

Ver también (no editar): help.extruder, help.winder, help.analysis, help.config, help.console, help.hardware

### Extrusor

ID: help.extruder Padre: help.global.tabs [sección]

Título

Extrusor

Resumen (una línea)

—

Cuerpo

Extrusión en vivo en el MK3S+: inicio/parada, consignas, asistente predictivo, receta de material, monitoreo de diámetro y gráficos de telemetría.

Ver también (no editar): help.tips

### Controles

ID: help.extruder.controls Padre: help.extruder

Título

Controles

Resumen (una línea)

INICIAR/PARAR extrusor, modo pull, enfriamiento y precalentamiento.

Cuerpo

Controles -
INICIAR EXTRUSOR comienza la extrusión en el MK3;
PARAR EXTRUSOR termina la corrida.
PULL AUTO / PULL MANUAL alterna si el RPM de bobinado sigue la receta o consignas manuales.
COOLDOWN y PREHEAT envían presets térmicos rápidos.
Nota: Los controles se deshabilitan mientras el bobinador controla la máquina (RUN o PAUSA en la pestaña bobinador).

Ver también (no editar): help.extruder.setpoints, help.winder.controls

### Consignas (R / T / F / P)

ID: help.extruder.setpoints Padre: help.extruder

Título

Consignas (R / T / F / P)

Resumen (una línea)

Editar RPM sinfín, temperatura, ventilador y RPM pull.

Cuerpo

Consignas - Muestra real vs objetivo para velocidad sinfín (R), temperatura nozzle (T), ventilador (F) y RPM pull (P). Pulse EDITAR para cambiar objetivos, luego APLICAR para enviarlos al MK3. En modo PULL MANUAL el objetivo pull es editable; en PULL AUTO sigue la receta del material.

Ver también (no editar): help.extruder.material, help.extruder.controls

### Estado en vivo

ID: help.extruder.live-status Padre: help.extruder

Título

Estado en vivo

Resumen (una línea)

Líneas clave del último poll STATUS del gateway.

Cuerpo

Estado en vivo - Resume las líneas más importantes de la respuesta STATUS periódica: diámetro (D:), estado del extrusor e info de sesión. Se actualiza con la barra de poll en la franja de estado. Si está vacío, espere a que el enlace del gateway se ponga verde.

Ver también (no editar): help.global.connection, help.global.polling

### Asistente predictivo

ID: help.extruder.predictor Padre: help.extruder [sección]

Título

Asistente predictivo

Resumen (una línea)

Corrección manual o automática de diámetro (reglas R / T). Códigos LCD/Flutter.

Cuerpo

Códigos del predictor (LCD / Flutter)
SIN A / - - Auto OFF o predictor deshabilitado (PREDEN=0)
A - Auto ON, sin Δ E/T este ciclo
AH - Hold de transporte (espera metros/tiempo tras un correctivo)
AB - Diámetro en banda (cerca del objetivo → no corrige)
AS - Settling T (espera tras cambio de temperatura)
AC - Hall sin calibrar (CALV=0)
AO - Hall off (DH=0; FW actual fuerza DH=1)
AG - Aún no puede corregir: falta alguna condición de marcha (extrusor no en START/RUN, pull en MANUAL en vez de AUTO, o temperatura real lejos del objetivo |Tact−Ttgt|)
AN - Sin muestras de diámetro en la ventana
AP - Patinaje: aviso; actúa solo con Optimizar ON (|ΔE|≥2 rpm y P no sigue 90 s)
AU - No fusión: misma prueba E/P con T baja (actúa solo con Optimizar ON)
AZ - Freeze 90 s tras emergencia (no optimizar P)
AE+ / AE- - Aplicó corrección de E (sube / baja)
AT+ / AT- - Aplicó corrección de T (sube / baja)
Tabla imprimible de taller: Consejos y trucos → Códigos LCD del predictor.

Asistente predictivo - Muestra estado del predictor, correcciones sugeridas y reglas en vivo (ΔR / ΔT). Alterne Manual / automático en el interruptor del panel, o abra el icono de engranaje para parámetros PRED completos. El desplegable Perfil ofrece tres presets integrados (Conservador, Equilibrado, Agresivo) para recargar todos los límites como base; Equilibrado coincide con recomendaciones de producción. Active "Mostrar ayuda detallada" en ese diálogo para códigos, presets y campos.

Contrato
El predictor no mezcla Analog A3, Digital USB y Manual. Las tres fuentes llegan a un solo diámetro. Auto y Optimizar no saben de qué sensor vino.
Pulling debe estar en AUTO para que el predictor actúe. En pull MANUAL solo se muestra estado.

Diámetro
- Analog A3: promedio reciente del sensor Hall de la máquina.
- Digital USB: último valor del sensor USB. Si no llega dato durante 5 s, el predictor espera (no usa el Hall).
- Manual: el valor de calibre que usted carga. Queda válido aunque no lo cambie; no hace falta recargarlo cada 5 s.
Al cambiar de fuente se descarta lo anterior. A3 no usa USB/Manual. USB y Manual no usan el Hall.

Auto ON, Optimizar OFF (uso normal)
Si el diámetro está en banda (cerca del objetivo): no cambia RPM del sinfín ni temperatura.
Si está fuera de banda: corrige primero el sinfín y después la temperatura, y espera a que el material llegue al sensor.
Patinaje / no fusión: solo aviso en pantalla (AP / AU). No cambia consignas.

Auto ON, Optimizar ON
Úselo cuando el filamento ya sea dimensionalmente estable y desee buscar el punto óptimo de velocidad de tiraje y consumo energético sin comprometer la tolerancia de ±0,03 mm.
Igual que arriba para el diámetro. Además, si el diámetro lleva ~90 s cerca de banda, busca el objetivo de eficiencia P* (editable junto a Optimizar): P* es el tiraje (P) deseado mientras PULL sigue en Auto. El optimizador mueve sinfín (E/R) y temperatura (T) juntos para que el Auto suba o baje P. Nunca comanda P ni pasa a Manual. El Ø puede pasarse un poco de la banda muerta; si sale claro, vuelve la corrección normal de diámetro. Espere el hold de transporte entre pasos.
Detector de extremos (solo actúa con Optimizar ON): si el sinfín cambió 2 rpm o más (sube o baja) y el pulling no se movió, durante al menos 90 s: temperatura alta → patinaje (AP), baja un poco sinfín y/o temperatura; temperatura baja → no fusión (AU), sube temperatura. Luego pausa 90 s sin optimizar.

Firmware MK3 antiguo - Analog A3, extrusión, bobinado y predictor Auto siguen funcionando. Optimizar y P* aparecen solo si el QUERY del MK3 trae PREDOPT / PREDPSTAR. Digital USB y Manual aparecen solo si el QUERY trae DIAMSRC. Actualice el firmware del Mega para esas funciones extra.

Ver también (no editar): help.extruder.predictor.limits, help.extruder.diameter-alerts, help.config.hall, help.tips.use-predictor, help.tips.optimize-yield, help.tips.extreme-zones, help.tips.predictor-codes

### Editar límites del predictor (engranaje)

ID: help.extruder.predictor.limits Padre: help.extruder.predictor [sección]

Título

Editar límites del predictor (engranaje)

Resumen (una línea)

—

Cuerpo

Abra con el icono de engranaje en el panel del asistente predictivo. Edite parámetros PRED, elija modo Manual o Automático, seleccione preset Perfil (Conservador, Equilibrado o Agresivo) para recargar el paquete completo como punto de partida, y APLIQUE comandos PRED SET cambiados al MK3. Los superusuarios pueden Guardar perfiles globalmente en Firebase. Active "Mostrar ayuda detallada" en el diálogo: empieza con los códigos LCD/Flutter del predictor (SIN A, A, AH, AB, AS, AC, AO, AG, AN, AP, AU, AZ, AE±, AT±), luego ajustes recomendados, presets y campos.

Ver también (no editar): help.extruder.predictor.enabled, help.extruder.predictor.mode, help.extruder.predictor.target-d

### Activar asistente (Predictor ON/OFF)

ID: help.extruder.predictor.enabled Padre: help.extruder.predictor.limits

Título

Activar asistente (Predictor ON/OFF)

Resumen (una línea)

Interruptor maestro PREDEN. Recomendado: ON.

Cuerpo

Activar asistente - Interruptor maestro del predictor (PREDEN). En OFF no hay correcciones automáticas ni manuales aunque los límites estén cargados. En ON, el asistente evalúa error de diámetro cada ciclo CSV según Modo y compuertas de seguridad. Recomendado: ON.

### Modo (Manual / Automático)

ID: help.extruder.predictor.mode Padre: help.extruder.predictor.limits

Título

Modo (Manual / Automático)

Resumen (una línea)

Manual solo sugiere; Automático aplica correcciones.

Cuerpo

Modo - Manual calcula sugerencias Î"R/Î"T y las muestra sin enviar cambios al MK3. Automático aplica correcciones dentro de Emin/Emax, Tmin/Tmax y límites de paso. Recomendado: Manual al afinar material nuevo; cambie a Automático cuando el diámetro sea estable.

### Perfil

ID: help.extruder.predictor.profile Padre: help.extruder.predictor.limits [sección]

Título

Perfil

Resumen (una línea)

Recargar todos los campos del predictor desde un preset.

Cuerpo

Perfil - Desplegable en el diálogo de engranaje con cuatro opciones. Conservador, Equilibrado y Agresivo son tres presets integrados: seleccionar uno recarga cada límite numérico y ganancia en el formulario (forma rápida de reiniciar o cambiar estrategia). Personalizado significa edición local; no carga paquete hasta elegir de nuevo un preset con nombre. Modo, Activar asistente y CYCLE se conservan del borrador actual al cambiar presets. Pulse APLICAR para enviar solo valores PRED SET cambiados al MK3. Superusuarios pueden Guardar el paquete en Firebase (sobrescribe el preset integrado para ese nombre en todos los tótems). Punto de partida recomendado: Equilibrado.

Ver también (no editar): help.extruder.predictor.profile.conservative, help.extruder.predictor.profile.balanced, help.extruder.predictor.profile.aggressive

### Conservador (preset)

ID: help.extruder.predictor.profile.conservative Padre: help.extruder.predictor.profile

Título

Conservador (preset)

Resumen (una línea)

Correcciones suaves, banda RPM estrecha, deadband amplio.

Cuerpo

Conservador - Preset integrado para corridas estables con mínima intervención. Estos valores vienen cargados por defecto pero el usuario puede grabar a su preferencia cada perfil.

### Equilibrado (preset)

ID: help.extruder.predictor.profile.balanced Padre: help.extruder.predictor.profile

Título

Equilibrado (preset)

Resumen (una línea)

Valores recomendados de producción; punto de partida habitual.

Cuerpo

Equilibrado - Preset integrado alineado con ajustes de producción recomendados. Estos valores vienen cargados por defecto pero el usuario puede grabar a su preferencia cada perfil.

### Agresivo (preset)

ID: help.extruder.predictor.profile.aggressive Padre: help.extruder.predictor.profile

Título

Agresivo (preset)

Resumen (una línea)

Respuesta más rápida, deadband ajustado, pasos de corrección mayores.

Cuerpo

Agresivo - Preset integrado para corridas difíciles o deriva rápida de diámetro. Estos valores vienen cargados por defecto pero el usuario puede grabar a su preferencia cada perfil.

### DIAM debug CSV

ID: help.extruder.predictor.diam-debug Padre: help.extruder.predictor.limits

Título

DIAM debug CSV

Resumen (una línea)

Columnas diagnósticas extra en CSV MK3. Recomendado: ON.

Cuerpo

DIAMDEBUG - Añade columnas diagnósticas compactas al flujo CSV del MK3 (rechazos FIFO, estado debounce de mediana, mediana cruda vs publicada). Ãštil para verificar Salto mediana / Confirmación mediana. Recomendado: ON durante afinado y monitoreo.

### Objetivo D mm

ID: help.extruder.predictor.target-d Padre: help.extruder.predictor.limits

Título

Objetivo D mm

Resumen (una línea)

Diámetro nominal del filamento. Recomendado: 1,75 mm.

Cuerpo

Objetivo D mm - Diámetro nominal del filamento. Deadband, error y bandas de alerta se calculan respecto a este valor. Debe coincidir con la especificación de la bobina. Recomendado: 1,75 mm.

### Media banda D mm (Deadband/2)

ID: help.extruder.predictor.deadband Padre: help.extruder.predictor.limits

Título

Media banda D mm (Deadband/2)

Resumen (una línea)

Mitad del deadband alrededor de D objetivo. Recomendado: 0,03 mm.

Cuerpo

Media banda D mm - Mitad del deadband total (Deadband/2). Dentro de objetivo +/- banda el predictor no corrige. Banda más amplia = menos correcciones; más estrecha = más sensible. Recomendado: 0,03 mm.

### |Tact-Ttgt| máx degC (Coincidencia T)

ID: help.extruder.predictor.temp-match Padre: help.extruder.predictor.limits

Título

|Tact-Ttgt| máx degC (Coincidencia T)

Resumen (una línea)

Máx |real-objetivo| T para habilitar predictor. Recomendado: 2 degC.

Cuerpo

|Tact-Ttgt| máx - Si la temperatura real del nozzle difiere del objetivo RTF más que este valor, se inhibe la corrección predictiva hasta que T se estabilice. Evita correcciones durante calentamiento o transitorios grandes de T. Recomendado: 2 degC.

### Salto mediana mm (Med Salto)

ID: help.extruder.predictor.jump-debounce Padre: help.extruder.predictor.limits

Título

Salto mediana mm (Med Salto)

Resumen (una línea)

Umbral de salto grande de mediana (DIAMJDB). Recomendado: 0,15 mm.

Cuerpo

Salto mediana mm - La mediana móvil ~10 s debe cambiar al menos esta cantidad respecto a la última mediana publicada para tratarse como salto grande. Los saltos grandes quedan pendientes de confirmación en lugar de aplicarse de inmediato, filtrando picos y fallos del sensor. Recomendado: 0,15 mm.

### Confirmación mediana mm (Med conf)

ID: help.extruder.predictor.jump-confirm Padre: help.extruder.predictor.limits

Título

Confirmación mediana mm (Med conf)

Resumen (una línea)

Tolerancia de confirmación para salto pendiente (DIAMJPM). Recomendado: 0,06 mm.

Cuerpo

Confirmación mediana mm - Tras un salto grande pendiente, la mediana cruda de la siguiente ventana debe coincidir con el candidato dentro de +/- esta tolerancia antes de que el MK3 publique la nueva mediana. Recomendado: 0,06 mm.

### Emin (sinfín)

ID: help.extruder.predictor.e-min Padre: help.extruder.predictor.limits

Título

Emin (sinfín)

Resumen (una línea)

RPM mínimo del sinfín para correcciones. Recomendado: 9.

Cuerpo

Emin - Límite inferior de RPM que el asistente puede solicitar al corregir vía velocidad sinfín. Evita bloqueo o interrupción de flujo. Recomendado: 9 rpm.

### Emax (sinfín)

ID: help.extruder.predictor.e-max Padre: help.extruder.predictor.limits

Título

Emax (sinfín)

Resumen (una línea)

RPM máximo del sinfín para correcciones. Recomendado: 32.

Cuerpo

Emax - Límite superior de RPM para correcciones sinfín. Limita sobreaceleración y oscilación por saturación. Recomendado: 32 rpm.

### Tmin

ID: help.extruder.predictor.t-min Padre: help.extruder.predictor.limits

Título

Tmin

Resumen (una línea)

Límite térmico inferior del asistente. Recomendado: 174 degC.

Cuerpo

Tmin - Límite térmico inferior para correcciones de temperatura del predictor (no cambia por sí solo la consigna RTF base). Recomendado: 174 degC.

### Tmax

ID: help.extruder.predictor.t-max Padre: help.extruder.predictor.limits

Título

Tmax

Resumen (una línea)

Límite térmico superior del asistente. Recomendado: 189 degC.

Cuerpo

Tmax - Límite térmico superior para correcciones de temperatura del predictor. Mantiene el canal T en una ventana de proceso segura. Recomendado: 189 degC.

### CYCLE

ID: help.extruder.predictor.cycle Padre: help.extruder.predictor.limits

Título

CYCLE

Resumen (una línea)

Periodo de fusión fijo: 2 s (no configurable por operador).

Cuerpo

CYCLE - Periodo interno de fusión del predictor MK3, fijo en 2 segundos. El CSV por USB es on-demand (CSVQ); ya no es un ajuste 5/10 s. Tras cada fusión puede actuar, esperar T settle, o el hold de transporte (Hold transport m) por el recorrido boquilla->sensor.

### dR min (dE min)

ID: help.extruder.predictor.delta-e-min Padre: help.extruder.predictor.limits

Título

dR min (dE min)

Resumen (una línea)

Paso mínimo RPM por ciclo. Recomendado: 0,05.

Cuerpo

dE min - Corrección mínima de RPM sinfín por ciclo cuando actúa el canal R. Evita micro-pasos inefectivos. Recomendado: 0,05 rpm.

### dR max (dE max)

ID: help.extruder.predictor.delta-e-max Padre: help.extruder.predictor.limits

Título

dR max (dE max)

Resumen (una línea)

Paso máximo RPM por ciclo. Recomendado: 0,6.

Cuerpo

dE max - Cambio máximo de RPM sinfín por ciclo. Limita correcciones bruscas que podrían alterar el flujo. Recomendado: 0,6 rpm.

### kSpan R (kSpan E)

ID: help.extruder.predictor.kspan-e Padre: help.extruder.predictor.limits

Título

kSpan R (kSpan E)

Resumen (una línea)

Ganancia R por distancia a la banda. Recomendado: 10.

Cuerpo

kSpan E - Ganancia proporcional para correcciones sinfín según qué tan lejos está el diámetro fuera del deadband (componente span). Mayor = respuesta más fuerte fuera de banda. Recomendado: 10.

### kErr R (kErr E)

ID: help.extruder.predictor.kerr-e Padre: help.extruder.predictor.limits

Título

kErr R (kErr E)

Resumen (una línea)

Ganancia R por error de diámetro. Recomendado: 15.

Cuerpo

kErr E - Ganancia proporcional para correcciones sinfín según error absoluto de diámetro. Aumentar acelera respuesta R pero puede causar sobrepaso. Recomendado: 15.

### dT min degC

ID: help.extruder.predictor.delta-t-min Padre: help.extruder.predictor.limits

Título

dT min degC

Resumen (una línea)

Paso térmico base deseado por ciclo. Recomendado: 0,2 degC.

Cuerpo

dT min - Cambio de temperatura deseado/base por ciclo cuando el canal T está activo. Recomendado: 0,2 degC.

### dT max degC

ID: help.extruder.predictor.delta-t-max Padre: help.extruder.predictor.limits

Título

dT max degC

Resumen (una línea)

Tope de dT aplicado por ciclo. Recomendado: 1 degC.

Cuerpo

dT max - Tope duro de cambio de temperatura por corrección (dT aplicado = min(deseado, máx)). Mantener bajo por inercia térmica del nozzle. Recomendado: 1 degC.

### kSpan T

ID: help.extruder.predictor.kspan-t Padre: help.extruder.predictor.limits

Título

kSpan T

Resumen (una línea)

Ganancia T por distancia a la banda. Recomendado: 15.

Cuerpo

kSpan T - Ganancia térmica según distancia fuera del deadband (componente span del canal T). Recomendado: 15.

### kErr T

ID: help.extruder.predictor.kerr-t Padre: help.extruder.predictor.limits

Título

kErr T

Resumen (una línea)

Ganancia T por error de diámetro. Recomendado: 55.

Cuerpo

kErr T - Ganancia térmica según error absoluto de diámetro. Valores altos corrigen más rápido pero pueden causar caza térmica. Recomendado: 55.

### Margen R->T (Margen E)

ID: help.extruder.predictor.e-margin Padre: help.extruder.predictor.limits

Título

Margen R->T (Margen E)

Resumen (una línea)

Histéresis para pasar corrección R a T. Recomendado: 2 rpm.

Cuerpo

Margen E - Histéresis de RPM sinfín antes de que el predictor pueda pasar de correcciones R a T. Reduce alternancia entre canales. Recomendado: 2 rpm.

### Margen T->R (Margen T)

ID: help.extruder.predictor.t-margin Padre: help.extruder.predictor.limits

Título

Margen T->R (Margen T)

Resumen (una línea)

Histéresis para volver de corrección T a R. Recomendado: 2 degC.

Cuerpo

Margen T - Histéresis de temperatura antes de volver de correcciones T a R. Recomendado: 2 degC.

### Espera tras cambio T (Asentamiento T N)

ID: help.extruder.predictor.t-settle Padre: help.extruder.predictor.limits

Título

Espera tras cambio T (Asentamiento T N)

Resumen (una línea)

Fusiones tras corrección T. Rango: 15-20 (~30-40 s).

Cuerpo

Asentamiento T N - Tras un correctivo T, espera estas fusiones de 2 s antes de otra acción E/T (15 ~ 30 s ... 20 ~ 40 s; rango 15-20). Cubre inercia térmica del nozzle, no la distancia boquilla->sensor. Use Hold transport m para el recorrido del filamento hasta el sensor.

### Hold transporte m

ID: help.extruder.predictor.hold-m Padre: help.extruder.predictor.limits

Título

Hold transporte m

Resumen (una línea)

Metros de filamento a esperar tras E/T (boquilla->sensor). Recomendado: 0,50 m.

Cuerpo

Hold transporte m - Tras un correctivo E o T, espera hasta que la longitud extruida (L_m) avance esos metros, o hasta Hold timeout s. Ajústelo a la distancia física de salida de boquilla al sensor de diámetro. Muy bajo -> corrige antes de que el nuevo diámetro llegue al sensor; muy alto -> lento. Inicio recomendado: 0,50 m (ajuste a su máquina).

### Hold timeout s

ID: help.extruder.predictor.hold-timeout Padre: help.extruder.predictor.limits

Título

Hold timeout s

Resumen (una línea)

Espera máxima del hold de transporte. Recomendado: 60 s.

Cuerpo

Hold timeout s - Termina el hold de transporte si L_m se reinicia o el tiraje es demasiado lento para alcanzar Hold transport m. Evita que el predictor quede bloqueado. Recomendado: 60 s.

### Alertas de diámetro

ID: help.extruder.diameter-alerts Padre: help.extruder

Título

Alertas de diámetro

Resumen (una línea)

Avisos DLCD en la cabecera del predictor; pulse para recomendaciones.

Cuerpo

Alertas de diámetro - La insignia de color en la cabecera del asistente predictivo indica cuando el diámetro instantáneo (DLCD) está fuera de las bandas del predictor. Pulse para abrir recomendaciones de filamento fino o grueso. Para resolver paso a paso vea Consejos y trucos.

Ver también (no editar): help.tips.filament-thin, help.tips.filament-thick

### Material

ID: help.extruder.material Padre: help.extruder

Título

Material

Resumen (una línea)

Seleccione la receta y aplique R / T / F / P sugeridos.

Cuerpo

Material - Elija un material del catálogo del gateway. Los valores sugeridos de RPM sinfín, temperatura, ventilador y pull aparecen sobre el desplegable. APLICAR envía la receta al MK3. EDITAR abre el editor de material (nuevo, actualizar, eliminar colores y parámetros). ACTUALIZAR recarga la lista desde la Pi.

Nota: Niveles acumulados de masterbatch superiores al 5% pueden alterar la reología y viscosidad del polímero, requiriendo ajustes finos en las curvas de temperatura para evitar fragilidad en el filamento. Vea Consejos → Receta de mezcla y Homogeneizar el triturado.

Ver también (no editar): help.extruder.setpoints, help.tips.material-lots, help.tips.material-recipe, help.tips.two-pass-homogeneity, help.tips.grey-color-recipes

### Histograma

ID: help.extruder.histogram Padre: help.extruder

Título

Histograma

Resumen (una línea)

Gráfico de diámetro y RTF desde telemetría CSV en vivo.

Cuerpo

Histograma - Gráfica muestras recientes de telemetría: diámetro promedio (Davg) y opcionalmente E rpm, temperatura, ventilador y pull. GRABAR inicia el guardado del perfil CSV en la Pi; PARAR termina la grabación. LIMPIAR borra muestras locales sin afectar el log del gateway.

Ver también (no editar): help.analysis.histogram

### Bobinador

ID: help.winder Padre: help.global.tabs [sección]

Título

Bobinador

Resumen (una línea)

—

Cuerpo

Bobinado de filamento tras extrusión: velocidad, objetivo de metros, límites de diámetro, inicio/parada/pausa, calibración de offset y monitoreo de diámetro en vivo.

Ver también (no editar): help.extruder.controls

### Controles de bobinado

ID: help.winder.controls Padre: help.winder

Título

Controles de bobinado

Resumen (una línea)

INICIAR, PARAR, PAUSA/CONTINUAR y OFFSET.

Cuerpo

Controles de bobinado - INICIAR BOBINADO prepara el motor pull del MK3 e inicia la sesión. PARAR termina la sesión por completo. PAUSA baja el pull a 2 rpm (la sesión sigue activa); CONTINUAR restaura los 80 rpm estándar. OFFSET abre la calculadora de offset de diámetro (DLCD vs Dprom) para ajustar DOFF del sensor de diámetro. Los controles se deshabilitan mientras la pestaña extrusor controla la máquina sin bobinador.

Ver también (no editar): help.winder.parameters, help.winder.offset

### Parámetros

ID: help.winder.parameters Padre: help.winder

Título

Parámetros

Resumen (una línea)

RPM pull, objetivo de metros y ventana min/max de diámetro.

Cuerpo

Parámetros - RPM pull define velocidad de bobinado. El objetivo de metros es la meta de longitud del contador MK3. Diam min / max mm definen la ventana aceptable de diámetro promedio; cruzarla provoca pausa automática. EDITAR cambia valores localmente; APLICAR los envía al gateway. Metros acumulados muestra la longitud actual desde telemetría en vivo.

Ver también (no editar): help.winder.diameter-pause, help.winder.diameter-chart

### Gráfico de diámetro

ID: help.winder.diameter-chart Padre: help.winder

Título

Gráfico de diámetro

Resumen (una línea)

Histograma Davg en vivo con bandas de límite durante bobinado.

Cuerpo

Gráfico de diámetro - Gráfico móvil de diámetro promedio (Davg) desde telemetría CSV durante bobinado. Las líneas de referencia muestran la ventana min/max configurada y bandas de tolerancia. LIMPIAR reinicia muestras locales; el gateway sigue registrando mientras la sesión está activa.

Ver también (no editar): help.extruder.histogram

### Pausa por límite de diámetro

ID: help.winder.diameter-pause Padre: help.winder

Título

Pausa por límite de diámetro

Resumen (una línea)

Diálogo de pausa automática cuando Davg sale de la ventana min/max.

Cuerpo

Pausa por límite - Cuando el diámetro promedio sale de la ventana configurada durante el bobinado, el gateway pausa automáticamente y aparece este diálogo. Puede ajustar límites min/max, luego Continuar para enviar WINDER CONTINUE, o Parar para terminar la sesión. Vea Consejos y trucos para guía de filamento fino/grueso.

Ver también (no editar): help.tips.filament-thin, help.tips.filament-thick, help.winder.parameters

### Offset de diámetro (OFFSET)

ID: help.winder.offset Padre: help.winder

Título

Offset de diámetro (OFFSET)

Resumen (una línea)

Calcular y aplicar DOFF del sensor de diámetro desde DLCD vs Dprom.

Cuerpo

Offset de diámetro - Compara DLCD instantáneo con diámetro promedio móvil (Dprom) y propone un offset del sensor de diámetro (DOFF mm). Confirme para enviar HALL SET DOFF. Requiere MK3 conectado y lecturas válidas. También disponible en CONFIG -> Calibración del sensor de diámetro.

Ver también (no editar): help.config.hall

### Análisis

ID: help.analysis Padre: help.global.tabs [sección]

Título

Análisis

Resumen (una línea)

—

Cuerpo

Revisión offline de logs de producción guardados en la Pi (csv_logs). Explore historial de diámetro, navegue registros y encuentre eventos fuera de rango.

### Log de material (Pi csv_logs)

ID: help.analysis.material-log Padre: help.analysis

Título

Log de material (Pi csv_logs)

Resumen (una línea)

Staging siempre en G; al STOP se puede copiar al material elegido.

Cuerpo

Log de material - Las corridas en vivo siempre graban en csv_logs/G.csv (staging). Al STOP la app pregunta si copiar ese archivo sobre csv_logs/{seleccionado}.csv. Seleccione un material y cargue CSV FILE READ para perfiles guardados. ACTUALIZAR LISTA recarga materiales. Las cargas son solo lectura y no afectan la máquina en vivo.

Ver también (no editar): help.extruder.material

### Histograma

ID: help.analysis.histogram Padre: help.analysis

Título

Histograma

Resumen (una línea)

Gráfico de diámetro y tabla +/-5 registros alrededor de la fila seleccionada.

Cuerpo

Histograma - Grafica Davg (y trazas RTF opcionales) para la ventana visible alrededor del registro actual. Un marcador muestra el número de reg seleccionado. Debajo del gráfico, la tabla lista filas CSV +/-5 alrededor de la selección; pulse una fila para saltar. Las bandas de límite coinciden con umbrales de referencia del extrusor/bobinador.

Ver también (no editar): help.analysis.navigation

### VIEW y navegación de registros

ID: help.analysis.navigation Padre: help.analysis

Título

VIEW y navegación de registros

Resumen (una línea)

Span VIEW, botones paso, campo reg y filtro fuera de rango.

Cuerpo

VIEW y navegación - VIEW % define cuántas muestras son visibles alrededor del registro actual. Use < y > para un paso, << y >> para +/-10 filas. Escriba un número reg y Enter para saltar. Active filtro con umbrales Fino / Grueso: solo << y >> permanecen activos y saltan al siguiente registro con diámetro <= fino o >= grueso. Los mensajes indican "Filamento demasiado fino/grueso" o "No se encontraron registros fuera de rango".

Ver también (no editar): help.tips.filament-thin, help.tips.filament-thick

### Config

ID: help.config Padre: help.global.tabs [sección]

Título

Config

Resumen (una línea)

—

Cuerpo

Información de cuenta, detalles del gateway activo, WiFi y control LAN de la Raspberry Pi, opción de gateway en PC Windows, Raspberry Pi GW hardware y software, y calibración del sensor de diámetro MK3 (web). El cableado común del sensor está en Hardware (sensor).

### Cuenta

ID: help.config.account Padre: help.config

Título

Cuenta

Resumen (una línea)

Usuario conectado, rol, cerrar sesión y perfiles (superusuario).

Cuerpo

Cuenta - Muestra su correo, id de usuario Firebase y rol (Operador, Administrador o Superusuario). CERRAR SESIÓN termina la sesión. Los superusuarios ven PERFILES DE USUARIO para gestionar roles en Firebase. Los operadores usan solo EXTRUSOR, BOBINADOR, ANÁLISIS y CONFIG.

Ver también (no editar): help.global.roles, help.tips.operator-login

### Gateway activo

ID: help.config.gateway Padre: help.config

Título

Gateway activo

Resumen (una línea)

Estado online, token, hostname y cambiar gateway.

Cuerpo

Gateway activo - Muestra el tótem emparejado: online/offline, nombre amigable, token de 8 caracteres, clave gateway, hostname, MAC y serial cuando esté disponible. ACTUALIZAR actualiza desde Firebase. CAMBIAR GATEWAY abre el mismo selector que la barra de estado. Si el gateway o la nube están fuera de línea, los comandos de máquina se bloquean y Extrusor/Bobinador/Predictor/Consola quedan deshabilitados hasta que el gateway vuelva a estar en línea. El host puede ser Raspberry Pi Zero o un PC Windows dedicado (vea Gateway en PC Windows). Para primer emparejamiento vea Iniciar sesión (operador) en Consejos y trucos.

Ver también (no editar): help.global.gateway, help.tips.operator-totem, help.config.wifi.first-setup, help.config.windows-gateway

### Raspberry Pi GW (hardware y software)

ID: help.config.gateway.hardware Padre: help.config

Título

Raspberry Pi GW (hardware y software)

Resumen (una línea)

Tótem Pi Zero 2 W: imagen SD, cableado USB/alimentación, hotspot, conexión MK3S+.

Cuerpo

Raspberry Pi GW (hardware y software) - Tótem físico en el MK3S+ basado en Raspberry Pi Zero 2 W. Parte de B) Mk3s+Fr3dAddon ONLINE (no standalone). Flashee imagen de fábrica, cablee alimentación y USB, luego dé internet a la Pi vía hotspot addonfr3d.

Hardware
1) Raspberry Pi Zero 2 W
2) Cable micro USB a USB-A OTG (puerto USB datos Pi -> USB-A hembra para cable impresora)
3) Adaptador de alimentación micro USB +5 V 2 A (puerto PWR_IN Pi)
4) Micro SD 32 GB Clase 10
5) Cable USB-B a USB-A (puerto impresora MK3S+ -> adaptador OTG en la Pi)

Software
1) Descarga imagen de fábrica: https://github.com/dadonec-boop/MK3-FR3D-Addon/releases/download/pi-gateway-v0.8/fr3daddon-v0.8-small.img.zst (micro SD 32 GB Clase 10 o mayor)
2) Raspberry Pi Imager - Choose OS -> Use custom -> ese .img.zst -> Write

Conexiones
1) Conecte MK3S+ al Gateway FR3D Addon con cable USB-B a USB-A (USB-B impresora -> Pi vía adaptador OTG en puerto USB Pi, no PWR_IN).
2) Conecte la Pi a WiFi: SSID addonfr3d, contraseña addonfr3d (hotspot de fábrica; comparta internet del teléfono en primer arranque para registro en Firebase).

Tras cableado y flasheo, continúe con Configuración inicial del gateway para emparejamiento por token y login web. Alternativa PC Windows: Gateway en PC Windows (misma rama ONLINE).

Ver también (no editar): help.fr3d-addon.download, help.config.wifi.first-setup, help.config.setup-web, help.config.wifi, help.config.windows-gateway, help.config.hall.hardware, help.tips.operator-totem

### WiFi (Raspberry Pi)

ID: help.config.wifi Padre: help.config

Título

WiFi (Raspberry Pi)

Resumen (una línea)

Red conectada, agregar WiFi del sitio, perfiles guardados, conectar y eliminar.

Cuerpo

Panel WiFi - Gestione el WiFi del gateway Raspberry Pi Zero 2 W desde CONFIG.
WiFi conectado - Muestra el SSID activo (comando WIFI). ACTUALIZAR actualiza estado y lista guardada.
Nuevo WiFi - Ingrese SSID y contraseña, o pulse DISPONIBLES para escanear redes (WIFI AVAILABLE, ~30 s). ASIGNAR guarda el perfil (WIFI ADD), conecta (WIFI CONNECT) y verifica el enlace.
Redes guardadas - Perfiles en la Pi (WIFI LIST). CONECTAR cambia a una red guardada. ELIMINAR borra un perfil excepto el hotspot de fábrica addonfr3d, que no se puede quitar.
Red abierta - Use contraseña - al agregar una red sin clave.

Para el primer despliegue (imagen de fábrica, hotspot del teléfono, emparejamiento por token) vea Configuración inicial del gateway.

Ver también (no editar): help.config.setup-web, help.config.wifi.first-setup, help.config.gateway, help.tips.operator-login

### Gateway en PC Windows

ID: help.config.windows-gateway Padre: help.config

Título

Gateway en PC Windows

Resumen (una línea)

Ejecutar el gateway en un PC/notebook Windows sin Raspberry Pi Zero.

Cuerpo

Gateway en PC Windows - Alternativa al tótem Raspberry Pi Zero 2 W.

Cuándo usarlo - Un PC o notebook Windows dedicado junto a la extrusora, cable USB al MK3 e internet para Firebase. No hace falta hardware Pi, hotspot ni flashear SD.

Descarga - Desde Releases de MK3-FR3D-Addon (latest):
https://github.com/dadonec-boop/MK3-FR3D-Addon/releases/latest/download/FR3DGateway-windows-x64.zip
Descomprima en una carpeta y ejecute Iniciar_FR3DGateway.bat o FR3DGateway.exe.

Emparejamiento - Igual que en Pi: lea el token de 8 caracteres en el LCD del MK3 (Control -> addonfr3d-gateway / Windows), inicie sesión en https://fr3d-addon.web.app/ e ingrese el token. La presencia muestra hostType=windows.

CONFIG - Use Puerto COM (Windows) para listar/aplicar COMx. Los paneles WiFi / página LAN son solo Pi (ocultos o sin uso en Windows).

Actualizaciones - Administradores: en CONSOLA use WINDOWS UPDATE CHECK / HOWTO para el enlace. Cierre FR3DGateway, descomprima el paquete nuevo sobre la misma carpeta, conserve la configuración y vuelva a iniciar. Los comandos de update de Pi no aplican a Windows.

Ver también (no editar): help.config.serial-com, help.config.gateway.ota, help.config.wifi.first-setup, help.config.gateway, help.console.quick-commands

### Puerto COM (Windows)

ID: help.config.serial-com Padre: help.config

Título

Puerto COM (Windows)

Resumen (una línea)

Elegir y aplicar el puerto COM USB del MK3 cuando el gateway corre en Windows.

Cuerpo

Puerto COM (Windows) - Visible cuando el gateway emparejado es Windows.
SERIAL LIST - Actualizar lista COMx detectados y el puerto activo de config.
APLICAR COM - Envía SERIAL SET PORT y reconecta la sesión MK3 en ese puerto.
En Raspberry Pi este panel no se usa (USB by-id / UART se configuran en la Pi).
Vea también Gateway en PC Windows para instalación y actualización.

Ver también (no editar): help.config.windows-gateway, help.config.gateway, help.console

### App LAN y setup (Raspberry Pi)

ID: help.config.setup-web Padre: help.config

Título

App LAN y setup (Raspberry Pi)

Resumen (una línea)

Operar la máquina en la red local; WiFi en CONFIG; la nube sigue disponible.

Cuerpo

Operar en la red local (LAN) - Desde un celular, tablet o PC en la misma WiFi que la Raspberry Pi, abra la app de control en el navegador:
http://<IP-LAN-Pi>/
La app entra directo (sin login). Verá las mismas pantallas EXTRUSOR / BOBINADOR / CONFIG / CONSOLA que en la app en la nube, sin necesidad de Firebase.

WiFi - Cambie redes desde CONFIG -> WiFi en esa misma app (escanear, guardar, conectar).

Página de estado - Para ver la IP o MAC de la Pi:
http://<IP-LAN-Pi>:8080/ o http://<IP-LAN-Pi>/setup/

Internet / nube a la vez - Puede seguir usando https://fr3d-addon.web.app/ con emparejamiento por token del LCD. LAN y nube controlan la misma Pi; use una sesión a la vez para operar con claridad.

Cómo saber la IP de la Pi - Página de estado arriba, o CONFIG -> Gateway activo si la Pi está online, o en la lista de dispositivos del router. Tras unir la Pi a su WiFi suele verse una dirección 192.168.x.x.

Ver también (no editar): help.config.wifi, help.config.wifi.first-setup, help.config.gateway

### Configuración inicial del gateway

ID: help.config.wifi.first-setup Padre: help.config

Título

Configuración inicial del gateway

Resumen (una línea)

Flashear imagen Pi O zip Windows; emparejar token; login web.

Cuerpo

Dos opciones de host - Raspberry Pi Zero 2 W (tótem compacto) o un PC/notebook Windows dedicado junto a la extrusora (sin Pi). El emparejamiento Firebase y la UI web son los mismos.

Opción A - PC Windows - Vea Gateway en PC Windows: descargue FR3DGateway-windows-x64.zip, ejecute el exe (Firebase ya viene incluido), configure el COM en la web (CONFIG) y empareje con el token del LCD.

Opción B - Raspberry Pi (imagen de fábrica) - Descargue la imagen del gateway Pi Zero 2 W (solo binario):
https://github.com/dadonec-boop/MK3-FR3D-Addon/releases/download/pi-gateway-v0.8/fr3daddon-v0.8-small.img.zst
Página del release: https://github.com/dadonec-boop/MK3-FR3D-Addon/releases/tag/pi-gateway-v0.8
Flashee con Raspberry Pi Imager -> Use custom -> ese archivo .img.zst (SD de 32 GB o más).
La imagen incluye hotspot WiFi addonfr3d / addonfr3d para dar internet desde el teléfono y registrarse en Firebase.

Paso 1 (Pi) - Monte el hardware del gateway (ver FR3D Addon Gateway - hardware), flashee la imagen como arriba y conecte el MK3S+ a la Pi con cable USB-B a USB-A vía adaptador OTG.
Paso 2 - Encienda el gateway. En el teléfono (Pi), conéctese al WiFi addonfr3d (contraseña addonfr3d); en Windows use la red del PC como de costumbre.
Paso 3 - Espere hasta que el gateway se registre en el MK3S+. Lea el token de 8 caracteres: menú Control -> addonfr3d-gateway.
Paso 4 - Abra https://fr3d-addon.web.app/, cree cuenta (correo + contraseña) e inicie sesión.
Paso 5 - En el primer login la app pide el token del MK3S+. Escríbalo exactamente; la app verifica que el gateway esté catalogado en Firebase y lo vincula a su cuenta.
Paso 6 - Emparejamiento completo. Ya puede controlar la máquina desde la interfaz web.

Recomendación (Pi) - Durante el primer login mantenga la Pi encendida, conectada al MK3S+ vía USB OTG y online (hotspot del teléfono o WiFi del sitio). Tras emparejar, use el panel WiFi en CONFIG para agregar su red permanente del sitio.

Ver también (no editar): help.config.windows-gateway, help.config.wifi, help.config.setup-web, help.config.gateway, help.config.gateway.hardware, help.config.gateway.ota, help.tips.operator-login, help.tips.operator-totem

### Actualizar gateway

ID: help.config.gateway.ota Padre: help.config

Título

Actualizar gateway

Resumen (una línea)

Pi: actualizar desde CONSOLA. Windows: descargar zip y reemplazar archivos.

Cuerpo

Actualizar gateway - Al arrancar, la app comprueba si hay un programa de gateway más nuevo y pregunta Sí/No (todos los perfiles, incluido operador). Los botones de CONSOLA PI UPDATE / WINDOWS UPDATE también están para todos los perfiles.

Raspberry Pi - Elija Sí, o en CONSOLA envíe PI UPDATE GATEWAY latest. Espere alrededor de un minuto (el tótem puede desconectarse un momento al reiniciar). Luego envíe PI UPDATE STATUS para confirmar que terminó. Actualiza el software del gateway en la SD; no hace falta una imagen nueva para updates de rutina.

PC Windows - En CONSOLA use WINDOWS UPDATE CHECK (si hay paquete más nuevo) y WINDOWS UPDATE HOWTO (enlace de descarga). Cierre FR3DGateway, descargue el zip, descomprima sobre la misma carpeta y conserve su archivo de configuración. Luego vuelva a iniciar.

No mezcle paquetes Pi y Windows. Vea también Gateway en PC Windows.

Ver también (no editar): help.config.windows-gateway, help.config.wifi.first-setup, help.console, help.console.input, help.config.gateway

### Calibración del sensor de diámetro

ID: help.config.hall Padre: help.config

Título

Calibración del sensor de diámetro

Resumen (una línea)

Fuente A3/USB/Manual, cal A3 6 puntos (1.50–2.00), MEDIR / APLICAR, DOFF.

Cuerpo

Calibración del sensor de diámetro (web) - CONFIG -> Calibración del sensor de diámetro.

Fuente del sensor (exclusiva) - Elija un solo camino de Ø (CONFIG y LCD Source del MK3):
- Analógico A3 - Sensor Hall u óptico en el pin A3 del Mega. Calibre con Pattern / MEDIR / APLICAR; el predictor usa ese Ø en vivo.
- Digital USB (BDWidth) - Sensor BDWidth USB en el gateway (Pi/PC). Hall y calibración A3 off; el Ø llega por el sensor USB.
- Manual (mock) - Sin sensor físico. Cargue Ø fijo en EXTRUSOR (predictor “Ø ingreso manual” −[xx]+) o en el LCD MK3 (D mm). Para pruebas o sin sonda montada.

Firmware MK3 antiguo - Si faltan Digital USB y Manual, solo está Analógico A3. Actualice el firmware del Mega MK3 (o pida soporte) para habilitar las otras fuentes. Los menús Source en el LCD aparecen solo en firmware que los incluye.

Sensores soportados - La misma calibración A3 aplica a un sensor de diámetro de efecto Hall (montaje mecánico tipo INFIDEL) o a un sensor óptico de diámetro (basado en ARTME 3D). Ambos entregan realimentación de diámetro en el MK3; vea Hardware para cableado y piezas.

Calibración Analog A3 (firmware MK3 actual) - Un solo patrón de 6 puntos: 1.50, 1.60, 1.70, 1.80, 1.90, 2.00 mm. No hay cambio Pattern A/B. Coloque cada patrón físico, pulse MEDIR (ADC A3 en vivo) y APLICAR en la fila (guarda en MK3 + EEPROM). CALV=1 solo si los seis ADC son distintos y monótonos (todos suben o todos bajan). Flashear este firmware borra una cal Hall de 3 puntos previa (EEPROM V32).

Firmware MK3 antiguo (3 puntos) - Si el panel sigue mostrando Pattern Diameter A/B, el Mega no se reflasheó. El preset B (1.7/1.75/2.0) es el de fábrica; el A es 1.5/1.7/2.0. Capture Lo/Mid/Hi. La app web lo detecta sola (sin CALN,6) y mantiene la UI A/B.

OFFSET (DOFF) - Corrección sistemática de diámetro (-0.20...0.20 mm). El predictor no actúa hasta CALV=1.

LCD: AddonFR3D -> Diameter Sensor -> Source / 6-pt 1.5-2.0 / Need Calibrate! o CALIBRATE.
Hardware: Ayuda -> Hardware del sensor de diámetro.
Si Need Calibrate! no desaparece o el Ø queda congelado: Consejos → Calibración del sensor: solución de problemas.

Ver también (no editar): help.config.hall.hardware, help.config.gateway.hardware, help.mk3.hall-lcd-calibration, help.hardware, help.winder.offset, help.tips.sensor-calibrate

### Consola

ID: help.console Padre: help.global.tabs [sección]

Título

Consola

Resumen (una línea)

—

Cuerpo

Pestaña CONSOLA - Interfaz de comandos al gateway emparejado vía Firebase (visible para todos los perfiles). Todos los perfiles pueden actualizar el gateway (PI UPDATE / WINDOWS UPDATE) con los botones o con el Sí/No al arrancar. Los administradores tienen texto libre excepto SO y PI destructivos (STATUS/REINICIAR). Los superusuarios tienen acceso completo, incluidos comandos críticos del SO. Los operadores solo usan botones rápidos (sin texto libre ni ayuda de consola). Use con cuidado en una máquina de producción en vivo.

Ver también (no editar): help.global.tabs, help.global.roles, help.config.gateway.ota

### Salida de log

ID: help.console.output Padre: help.console

Título

Salida de log

Resumen (una línea)

Log de comandos desplazable con tráfico de poll automático.

Cuerpo

Salida de log - Muestra comandos salientes y respuestas del gateway en orden cronológico. Los polls automáticos STATUS/CSV/WINDER pueden ocultarse con Mostrar auto / Ocultar auto. Limpiar borra líneas locales sin afectar la Pi.

Ver también (no editar): help.console.quick-commands

### Entrada de comandos

ID: help.console.input Padre: help.console

Título

Entrada de comandos

Resumen (una línea)

Escriba comandos FR3D/MK3 y pulse Enviar o Enter.

Cuerpo

Entrada de comandos - Ingrese cualquier comando permitido del gateway (p. ej. STATUS, WINDER STATUS, PRED, HALL STATUS). Todos los perfiles pueden ejecutar PI UPDATE / WINDOWS UPDATE. Los administradores no pueden ejecutar SO ni PI de reinicio/shell. Los comandos se encolan en el canal Firebase; espere la respuesta anterior antes de enviar otro si el canal está ocupado.

Ver también (no editar): help.console.quick-commands

### Accesos rápidos

ID: help.console.quick-commands Padre: help.console

Título

Accesos rápidos

Resumen (una línea)

HELP, WHOAREYOU, CONECTAR, WIFI, WINDOWS UPDATE, Limpiar.

Cuerpo

Accesos rápidos - Atajos: HELP (admin/superusuario; sin líneas SO/PI para admin), WHOAREYOU, CONECTAR, DESCONECTAR, WIFI. En host Windows, admin/super también ven WINDOWS UPDATE CHECK y WINDOWS UPDATE HOWTO (toque zip= en el log para descargar). Mostrar auto / Ocultar auto alterna polls automáticos. Limpiar borra el log. Los operadores ven los botones sin HELP ni texto libre.

Ver también (no editar): help.console.output, help.config.windows-gateway, help.config.gateway.ota

## Hardware (sensor)

ID: help.hardware Padre: help.fr3d-addon [sección]

Título

Hardware (sensor)

Resumen (una línea)

—

Cuerpo

Hardware común a A) Standalone y B) ONLINE: el sensor de diámetro en el MK3S+ (efecto Hall tipo INFIDEL u óptico ARTME 3D), cableado A3 y filtros EMI.

El tótem Raspberry Pi Zero 2 W (alimentación, USB, imagen SD) está documentado en B) ONLINE -> Pestañas -> CONFIG -> Raspberry Pi GW (hardware y software), no aquí.

Ver también (no editar): help.config.hall.hardware, help.config.gateway.hardware, help.mk3, help.global

### Hardware sensor de diámetro

ID: help.config.hall.hardware Padre: help.hardware

Título

Hardware sensor de diámetro

Resumen (una línea)

Opciones de sensor (efecto Hall/INFIDEL 9 STL u óptico ARTME 3D), cableado A3, filtros EMI.

Cuerpo

Hardware del sensor de diámetro - El MK3S+ puede usar:
1) Sensor de diámetro de efecto Hall - montaje mecánico tipo INFIDEL (9 piezas STL impresas; sensor lineal SS495A en A3 con filtros EMI).
2) Sensor óptico de diámetro - basado en el sensor óptico ARTME 3D.
La calibración (Capture 6 puntos 1.50…2.00 mm, o Pattern A/B en firmware antiguo) es la misma en LCD y en CONFIG web.

Qué hace el sensor de diámetro
El calibrador mide diámetro de filamento entre 1,5 y 2,5 mm (valores fuera de rango se limitan por razones mecánicas). La calibración se hace una vez en el montaje; la compensación OFFSET ajusta el cero después si la pantalla deriva.

Montaje mecánico - efecto Hall (estilo INFIDEL)
Imprima las 9 piezas STL de la figura de ayuda (cuerpos marcados INFIDEL, soporte vertical, casquillo/separador, bloque en L, fijaciones pequeñas, palanca/leva y pasador). El archivo de impresión es un único STL multi-cuerpo:
https://github.com/dadonec-boop/MK3-FR3D-Addon/raw/main/docs/diameter_sensor_infidel/Hall_Sensor_Parts.stl
STL folder: https://github.com/dadonec-boop/MK3-FR3D-Addon/tree/main/docs/diameter_sensor_infidel
Ábralo en el slicer y sepárelo en objetos/piezas individuales antes de imprimir (vea el README de esa carpeta). Ensamble con rodillo, imán y SS495A según el diseño de referencia INFIDEL:
https://www.printables.com/model/57154-infidel-inline-filament-diameter-estimator-lowcost
Monte el conjunto en el camino del filamento antes del puller (vea la foto ensamblada en este tema de ayuda).

Montaje óptico (ARTME 3D)
Siga la documentación del sensor óptico ARTME 3D para mecánica y óptica. La integración eléctrica con el MK3 sigue la entrada de diámetro del Addon FR3D (notas del kit).

Firmware MK3 FR3D (guía §4 - Carpeta MK3)
Paquete de software - Desktop-Filament-Extruder-MK3-FR3D (extraiga el .rar en su PC).
1) Abra la carpeta MK3 del paquete.
2) Cargue el proyecto en Arduino IDE (placa: Makerbase MKS Gen_L V2.1, Smart LCD 2004).
3) Suba el firmware addon FR3D MK3S+ a la placa principal MK3.

Este firmware habilita el camino del sensor de diámetro, predictor FR3D, menús LCD AddonFR3D y comunicación serial USB con el gateway Raspberry Pi. Una vez la Pi conectada al MK3 vía USB (tótem Gateway FR3D Addon), el gateway intercambia identidad con la impresora y se registra en Firebase - la Pi es incorporada por el enlace del firmware FR3D en ejecución. Continúe con Configuración inicial del gateway para WiFi y emparejamiento web.

Conexión hardware - efecto Hall en A3 (guía §3)
Placa principal: Makerbase MKS Gen_L V2.1. Conecte el sensor lineal de efecto Hall SS495A al header analógico (mismo bloque que sensor de curvatura A4).

Cableado
1) Verde - gnd sensor -> GND placa
2) Rojo - 5V sensor (Vin) -> 5V placa
3) Azul - a3 sensor (salida analógica) -> A3 placa

A3 está junto a A4. Obtenga GND y 5V del mismo conector donde están A3 y A4.

Filtro de reducción de ruido para el SS495A (opción efecto Hall)
Para proteger el sensible SS495A de interferencia electromagnética (EMI) de motores paso a paso y elementos calefactores, use filtrado en dos etapas: desacoplamiento de alimentación cerca del sensor y filtro RC paso bajo en la señal analógica cerca del controlador.

Etapa 1 - Desacoplamiento de alimentación (~4 cm del sensor)
Componentes
1) Un capacitor cerámico 0,1 µF (marca 104)
2) Un capacitor electrolítico 4,7 µF

Montaje del cableado
1) Conecte el terminal positivo (+) del electrolítico 4,7 µF (pata larga) a una pata del cerámico 0,1 µF.
2) Soldar ese nudo a la línea 5V (Vin).
3) Conecte el terminal negativo (-) del electrolítico (pata corta, franja) a la otra pata del cerámico.
4) Soldar ese nudo a GND.

El cable de salida (datos) del sensor bypassa este bloque y continúa hacia el controlador.

Etapa 2 - Filtrado de señal (filtro RC paso bajo)
Componentes
1) Una resistencia 1 kΩ
2) Un capacitor cerámico 10 nF (marca 103)

Montaje del cableado
1) Corte el cable de señal (salida) del sensor.
2) Suelde el cable entrante a un extremo de la resistencia 1 kΩ.
3) Suelde el otro extremo de la resistencia al pin analógico del microcontrolador (A3).
4) Coloque el capacitor 10 nF lo más cerca posible del pin A3 (idealmente menos de 4 cm, o en placa).
5) Una pata del capacitor a A3 (mismo nodo que resistencia); la otra a GND en placa.

Próximos pasos - Tras montaje mecánico, flasheo, cableado y filtros: calibrar con A) Standalone MK3S -> Sensor de diámetro (LCD) o B) ONLINE -> CONFIG -> Calibración sensor de diámetro (web).

Ver también (no editar): help.config.hall, help.mk3.hall-lcd-calibration, help.mk3.firmware, help.hardware

## Consejos y trucos

ID: help.tips Padre: help.fr3d-addon [sección]

Título

Consejos y trucos

Resumen (una línea)

—

Cuerpo

Guía práctica de taller: clasificar, tamizar y secar material, recetas y lotes, homogeneizar en dos pasadas, color sobre triturado gris, primeras corridas en Manual, comprobar el calibre, calibración del sensor, códigos LCD del predictor, filamento fino o grueso, zonas extremas, predictor y Optimizar.

### Clasificar los materiales

ID: help.tips.material-classes Padre: help.tips

Título

Clasificar los materiales

Resumen (una línea)

Al menos cuatro grupos: desecho de impresiones, piezas fallidas, pelletizado de filamento y virgen.

Cuerpo

Clasificar los materiales - No mezcle todo el plástico en una sola tolva. Al menos cuatro familias:

- Desecho de impresiones 3D - faldas, bordes, purgas y recortes de impresiones que sí salieron bien.
- Piezas fallidas - impresiones abortadas o rechazadas. Suelen mezclar colores y trozos más irregulares.
- Pelletizado de filamento 3D - filamento comercial pasado a pellet. Suele ser más parejo en tamaño y fusión.
- Virgen - pellet nuevo del proveedor de resina.

Cada familia funde distinto. Una receta que sirve en pelletizado no es la misma que en piezas fallidas trituradas. Etiquételas y no mezcle familias en el mismo lote.

Siguiente: triturar y tamizar, y poner número de lote a cada bolsa.

Ver también (no editar): help.tips.grind-sieve, help.tips.material-recipe, help.tips.material-lots, help.extruder.material

### Triturado y tamizado

ID: help.tips.grind-sieve Padre: help.tips

Título

Triturado y tamizado

Resumen (una línea)

Tras triturar, deje solo partículas entre 2,5 y 4,5 mm. Descarte el resto.

Cuerpo

Triturado y tamizado - El material triturado debe pasar por una tamizadora para que la tolva vea un tamaño de partícula parecido.

Conserve la fracción entre 2,5 mm y 4,5 mm. Descarte finos (polvo y hojuelas bajo 2,5 mm) y trozos grandes sobre 4,5 mm. Los finos se apelmazan, queman o hacen burbujas; los chips grandes ahogan el sinfín y hacen saltar el diámetro.

Tamice cada lote, aunque “ya se vea chico”. Después seque 4 a 8 horas, arme la receta 70 / 30 y haga la prueba de 50 g antes de un carrete largo.

Ver también (no editar): help.tips.material-classes, help.tips.dry-material, help.tips.material-recipe, help.tips.two-pass-homogeneity, help.tips.material-lots

### Secar el triturado (4 a 8 horas)

ID: help.tips.dry-material Padre: help.tips

Título

Secar el triturado (4 a 8 horas)

Resumen (una línea)

Seque el triturado 4 a 8 horas antes de extruir. El material húmedo da burbujas, saltos de diámetro y filamento frágil.

Cuerpo

Secar el triturado - La humedad es una de las causas principales de una corrida reciclada inestable. El plástico triturado tiene mucha superficie, así que toma agua mucho más rápido que el pellet virgen. Seque cada lote 4 a 8 horas antes de cargarlo en la tolva (secador de filamento u horno con circulación de aire, a la temperatura recomendada para ese polímero, nunca cerca de la fusión). Después cierre la bolsa.

Si el triturado no está bien seco suele verse:
- Vapor, silbido o “pop” en el nozzle.
- Burbujas, huecos y superficie esponjosa o rugosa en el filamento.
- Diámetro que salta fino y grueso aunque E y T estén fijos (el predictor no puede sostener 1,75 mm).
- Filamento débil y quebradizo, que se parte en el bobinador o imprime mal.
- En PETG, nylon y similares, el agua también ataca el polímero (hidrólisis): el fundido sigue mal aunque “afine” R y T.

Una prueba de 50 g con material húmedo pierde tiempo: perseguirá un diámetro que en realidad es vapor. Seque primero, después mezcle y pruebe.

Ver también (no editar): help.tips.grind-sieve, help.tips.material-recipe, help.tips.two-pass-homogeneity, help.tips.material-lots, help.tips.extreme-zones

### Receta de mezcla (70 / 30 / 3)

ID: help.tips.material-recipe Padre: help.tips

Título

Receta de mezcla (70 / 30 / 3)

Resumen (una línea)

Mezcla típica: 70% triturado, 30% virgen, hasta 3% colorante. Más virgen = más flexible; más triturado = más opaco.

Cuerpo

Receta de mezcla - Un buen punto de partida para filamento reciclado es:

- 70% triturado tamizado (2,5 a 4,5 mm)
- 30% pellet virgen
- hasta 3% de colorante (no pase de 3% salvo que ese lote ya esté probado)

Nota: Niveles acumulados de masterbatch superiores al 5% pueden alterar la reología y viscosidad del polímero, requiriendo ajustes finos en las curvas de temperatura para evitar fragilidad en el filamento.

Ajuste según el producto que busca:
- Más flexible / más brillo - suba el virgen y baje el triturado.
- Más opaco / más “cara de reciclado” - suba el triturado y baje el virgen.

Pese los porcentajes en la misma balanza, mezcle en seco, extruya 50 g de prueba y guarde R / T / F / P en ese lote. El 70 / 30 / 3 es un arranque, no una ley: el color, el polímero y el tamaño de partícula siguen cambiando la fusión.

Ver también (no editar): help.tips.grind-sieve, help.tips.dry-material, help.tips.two-pass-homogeneity, help.tips.grey-color-recipes, help.tips.material-lots, help.extruder.material

### Número de lote y prueba de 50 g

ID: help.tips.material-lots Padre: help.tips

Título

Número de lote y prueba de 50 g

Resumen (una línea)

Cada bolsa lleva número de lote. Extruya 50 g, halle R T F P y guárdelos en la tabla de materiales.

Cuerpo

Número de lote - Dos bolsas de la misma familia (por ejemplo ambas “desecho de impresiones”) no funden igual. La homogeneidad, el tamaño de chip, el color y aditivos residuales cambian el mejor R, T, F y P.

Cada vez que triture y clasifique un batch, póngale un número de lote (en la bolsa y en el nombre de la app, por ejemplo PLA-desecho-L014). No vuelque dos lotes a la vez en la tolva.

Tome al menos 50 g de ese lote, extrúyalo en Manual y busque el punto óptimo (flujo estable y diámetro cerca de 1,75 mm). Anote R (E rpm), T, F y P, y guárdelos en la tabla de materiales de la app (material nuevo o actualizar el existente).

La próxima vez que corra ese lote, seleccione el material y APLIQUE. Esos valores son el punto de partida; igual mire el diámetro. Si el lote se acabó, no reutilice esa fila para una bolsa nueva sin otra prueba de 50 g.

Ver también (no editar): help.tips.material-classes, help.tips.dry-material, help.tips.material-recipe, help.tips.two-pass-homogeneity, help.tips.grey-color-recipes, help.tips.first-time, help.extruder.material

### Primera vez: practique en Manual

ID: help.tips.first-time Padre: help.tips

Título

Primera vez: practique en Manual

Resumen (una línea)

Poca experiencia: extruya en diámetro Manual y mida con calibre a la salida del bobinador.

Cuerpo

Primera vez - Si es su primera extrusión, o todavía tiene poca práctica, use el modo de diámetro Manual. Así entiende qué hace cada consigna (E rpm del sinfín, temperatura T, ventilador F y pull P) sin que el predictor mueva la máquina por usted.

Cómo practicar
- Parta de una receta de material. No invente E y T desde cero.
- Mida el diámetro con un calibre, siempre a la salida del bobinador (el mismo punto cada vez).
- Cambie solo una o dos consignas y espere 30 a 60 segundos antes de volver a medir. El fundido tarda en llegar del nozzle al carrete.
- Anote E, T, F y P cuando la corrida se vea estable. Esa es su base.
- Mire la tendencia, no cada muestra suelta.

Si casi no sale filamento, es una zona extrema de fusión, no un ajuste de diámetro. Vea Zonas extremas. Cuando el flujo sea estable y el diámetro se acerque a 1,75 mm, puede pasar al sensor analógico o digital y después al predictor.

Ver también (no editar): help.tips.caliper-check, help.tips.extreme-zones, help.tips.material-lots, help.extruder.material, help.tips.use-predictor

### Homogeneizar el triturado (proceso de extrusión de dos pasadas)

ID: help.tips.two-pass-homogeneity Padre: help.tips

Título

Homogeneizar el triturado (proceso de extrusión de dos pasadas)

Resumen (una línea)

Triturado irregular: mezclar, secar, extruir ~2,4 mm, pelletizar y una segunda pasada a 1,75 mm.

Cuerpo

Homogeneizar el triturado - Cuando el plástico triturado es desigual (chips, color y fusión mezclados), una sola pasada a 1,75 mm suele dar saltos de diámetro y vetas. Este proceso de taller usa dos pasadas de extrusión: primero una hebra gruesa (~2,4 mm), pelletizar, y después una segunda pasada a 1,75 mm.

Paso 1 - Primera receta
- Separe el triturado por tipo de polímero. No mezcle familias en el mismo lote.
- Tamice para dejar partículas entre 2,5 mm y 4,5 mm. Descarte finos y trozos grandes.
- Agregue colorante masterbatch para buscar el tono: hasta un máximo de 3% de blanco o combinado con otro color.
- Agregue 20% de pellet virgen (~3 mm).
- Mezcle en seco (tumble blending) hasta que quede pareja.
- Seque 4 a 6 horas (temperatura de ese polímero, nunca cerca de la fusión).
- Guarde en una bolsa de vacío hasta extruir.

Paso 2 - Primera extrusión (~2,4 mm)
- Cambie la boquilla de la extrusora por una de 2,2 mm.
- Calibre en Manual para obtener un filamento entre 2,3 mm y 2,5 mm (promedio cerca de 2,4 mm).

Paso 3 - Receta final
- Pelletice el filamento de ~2,4 mm a unos 2,5 mm para igualar el tamaño del pellet virgen.
- Agregue 20% de pellet virgen de 3 mm.
- Solo si es muy necesario agregue colorante masterbatch hasta un máximo de 1%, del mismo color de antes, solo para reforzar el tono.
- Seque al menos 2 horas.

Paso 4 - Segunda extrusión (1,75 mm)
- Cambie la boquilla por una de 1,7 mm.
- Calibre con objetivo 1,75 mm, manteniendo la hebra entre 1,72 mm y 1,78 mm.

Ponga número de lote, haga la prueba de 50 g y guarde R / T / F / P. La mezcla simple 70 / 30 sigue sirviendo si el triturado ya es parejo; use dos pasadas cuando el shred es heterogéneo.

Nota: Niveles acumulados de masterbatch superiores al 5% pueden alterar la reología y viscosidad del polímero, requiriendo ajustes finos en las curvas de temperatura para evitar fragilidad en el filamento.

Ver también (no editar): help.tips.grind-sieve, help.tips.dry-material, help.tips.material-recipe, help.tips.grey-color-recipes, help.tips.material-lots, help.tips.first-time

### Comprobar el calibre

ID: help.tips.caliper-check Padre: help.tips

Título

Comprobar el calibre

Resumen (una línea)

Compare su calibre con filamento comercial 1,75 mm de calidad o una broca de 1,75 mm.

Cuerpo

Comprobar el calibre - Un calibre mal puede hacerle “corregir” un diámetro que ya está bien.

1) Tome un trozo de filamento comercial 1,75 mm de buena calidad, o una broca de 1,75 mm.
2) Mídalo con su calibre y anote la lectura (ejemplo: 1,78 mm).
3) La diferencia respecto a 1,75 mm es el error del instrumento (en el ejemplo, +0,03 mm).

Cuando mida el filamento que usted produce, aplique ese desfase. Si el calibre lee 1,78 mm sobre un patrón de 1,75 mm, una lectura de producción de 1,78 mm es en realidad unos 1,75 mm.

Mida siempre en el mismo punto (salida del bobinador) y no aplaste la hebra. Si usa sensor analógico A3 o digital USB, esta prueba sigue sirviendo para confirmar la lectura en vivo.

Ver también (no editar): help.tips.first-time, help.config.hall, help.mk3.hall-lcd-calibration, help.extruder.diameter-alerts, help.tips.sensor-calibrate

### Recetas de color sobre triturado gris claro

ID: help.tips.grey-color-recipes Padre: help.tips

Título

Recetas de color sobre triturado gris claro

Resumen (una línea)

Triturado gris claro más masterbatch amarillo, rojo, azul o verde da tonos apagados, pasteles o tierra.

Cuerpo

Recetas de color sobre triturado gris claro - Una base de polímero gris claro es un fondo de baja saturación y mucho blanco. Al mezclarla con un masterbatch de color puro no se comporta como una mezcla sustractiva de pigmentos primarios sobre virgen transparente o blanco. El resultado es un tono desaturado, pastel o tierra, según el color que agregue.

1) Masterbatch amarillo
- Resultado: amarillo verdoso claro, vainilla apagado o marfil grisáceo, según la concentración.
- Qué esperar: el triturado gris tiene base blanca/translúcida y partículas oscuras dispersas, así que el amarillo no brillará como sobre virgen transparente o blanco puro. Queda un crema con un matiz un poco deslucido o industrial.

2) Masterbatch rojo
- Resultado: rosa viejo, terracota suave, arcilla clara o salmón apagado.
- Qué esperar: el rojo sobre gris pierde viveza y se corre a gamas pasteles o terrosas. Sirve si busca una estética rústica o de arcilla en las piezas impresas.

3) Masterbatch azul
- Resultado: celeste grisáceo, gris azulado (acero/industrial) o azul perla.
- Qué esperar: una de las mezclas más agradecidas en reciclaje. El gris y el azul se complementan y dan un aspecto técnico y limpio, parecido al plástico de ingeniería gris industrial pero con un tinte frío claramente azulado.

4) Masterbatch verde
- Resultado: verde salvia claro, verde grisáceo (militar suave) o verde pastel desaturado.
- Qué esperar: como con el azul, el resultado se inclina a tonos orgánicos o de baja saturación (militar o naturaleza seca). Evita que el verde se vea neón y deja un acabado mate y sobrio.

Consejos de taller
- Empiece con 1% a 2% de masterbatch para ver cómo cubre el gris antes de saturar el tornillo.
- Si el triturado gris viene de varias fuentes, mezcle en seco (tumble blending) con el masterbatch para no tener vetas ni parches de color en el filamento.
- En la segunda pasada de un lote de dos pasadas, agregue color extra solo si es muy necesario, hasta 1%, y use el mismo color para reforzar el tono.

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

Ver también (no editar): help.tips.two-pass-homogeneity, help.tips.material-recipe, help.tips.grind-sieve, help.tips.material-lots

### Filamento demasiado fino

ID: help.tips.filament-thin Padre: help.tips

Título

Filamento demasiado fino

Resumen (una línea)

Bajo el objetivo: suba un poco E, baje T, más ventilador, sensor más cerca del nozzle.

Cuerpo

Filamento demasiado fino - El diámetro promedio (Davg) está bajo la ventana. Cambie una o dos consignas, espere 30 a 60 segundos y vuelva a medir a la salida del bobinador.

1) E rpm del sinfín - Suba un poco E para que salga más fundido (hebra más gruesa).
2) Temperatura T - Baje un poco T para que el fundido sea más viscoso y se estire menos.
3) Ventilador F - Suba F para que la hebra solidifique antes y se estire menos con el tiraje.
4) Distancia del sensor - Acerque el sensor de diámetro al nozzle (menos recorrido de estirado).
5) Posición del ventilador - Si el conducto se puede mover, acérquelo al nozzle para enfriar más.
6) Compruebe el instrumento - Confirme que el calibre o el sensor no lean de menos (vea Comprobar el calibre). Revise desgaste del orificio.
7) Receta - Menos reciclado (-T%) y más virgen (+V%) si el fundido está demasiado fluido.

No cambie E, T, F y la geometría a la vez: no sabrá qué hizo efecto.

Ver también (no editar): help.tips.filament-thick, help.tips.caliper-check, help.tips.extreme-zones, help.extruder

### Calibración del sensor: solución de problemas

ID: help.tips.sensor-calibrate Padre: help.tips

Título

Calibración del sensor: solución de problemas

Resumen (una línea)

Need Calibrate! trabado, Ø congelado o AC en el LCD: mire A3, limpie el sensor y compruebe que el Ø se mueve.

Cuerpo

Calibración del sensor: solución de problemas - Úselo si el LCD muestra Need Calibrate!, el predictor queda en AC, o el diámetro en vivo no sigue la hebra física.

- Voltaje en el pin A3 - Con fuente Analógico A3, mida la señal Hall/óptica en el pin A3 del Mega. Un cable cortado, en corto o suelto deja un voltaje fijo y el Ø no se mueve.
- Limpie el sensor - Polvo, viruta y grasa en el camino Hall u óptico congelan la lectura. Limpie la guía y la cara de medición, y vuelva a capturar los seis puntos (o Lo / Mid / Hi en firmware antiguo).
- Compruebe que el Ø no está estático - Cambie el diámetro físico (cambie un patrón de calibración, o apriete la hebra con cuidado). DXXXX en la pantalla principal debe cambiar. Si queda congelado, el sensor no ve el filamento: cableado, Source (A3 vs USB vs Manual) o suciedad.
- Complete todas las filas Capture hasta CALV=1 (seis puntos 1.50…2.00 en firmware actual; Lo / Mid / Hi en el antiguo). Los seis ADC deben ser distintos y monótonos. El predictor no actúa hasta entonces.
- Si Need Calibrate! queda con seis ADC iguales, A3 no ve un sensor real (pin abierto). Corrija el cableado o recapture con patrones reales.

LCD: Control -> AddonFR3D -> Diameter Sensor -> Need Calibrate! o CALIBRATE.

Ver también (no editar): help.mk3.hall-lcd-calibration, help.config.hall, help.tips.caliper-check, help.tips.predictor-codes

### Filamento demasiado grueso

ID: help.tips.filament-thick Padre: help.tips

Título

Filamento demasiado grueso

Resumen (una línea)

Sobre el objetivo: baje un poco E, suba T, menos ventilador, sensor más lejos del nozzle.

Cuerpo

Filamento demasiado grueso - El diámetro promedio (Davg) está sobre la ventana. Es lo contrario del filamento fino. Cambie una o dos consignas, espere 30 a 60 segundos y mida a la salida del bobinador.

1) E rpm del sinfín - Baje un poco E para que salga menos fundido (hebra más fina).
2) Temperatura T - Suba un poco T para que el fundido sea más fluido y pueda estirarse más.
3) Ventilador F - Baje F para que la hebra siga fundida más tiempo y se estire con el tiraje.
4) Distancia del sensor - Aleje el sensor de diámetro del nozzle (más recorrido de estirado).
5) Posición del ventilador - Si el conducto se puede mover, aléjelo un poco del nozzle.
6) Compruebe el instrumento - Confirme que el calibre o el sensor no lean de más (vea Comprobar el calibre). Revise desgaste del orificio.
7) Receta - Más reciclado (+T%) y menos virgen (-V%) si el fundido está demasiado rígido.

Ventilador y sensor van al revés que en filamento fino. Subir F o acercar el sensor suele hacer la hebra todavía más gruesa.

Ver también (no editar): help.tips.filament-thin, help.tips.caliper-check, help.tips.extreme-zones, help.extruder

### Zonas extremas (frío, calor y punto óptimo)

ID: help.tips.extreme-zones Padre: help.tips

Título

Zonas extremas (frío, calor y punto óptimo)

Resumen (una línea)

Muy frío: no funde o pierde pasos. Muy caliente: patina en el sinfín. Suba el rendimiento desde un P estable.

Cuerpo

Zonas extremas - Los ajustes de diámetro solo sirven cuando el plástico funde y agarra en el sinfín. Si casi no sale material, primero salga de la zona extrema.

A) Temperatura demasiado baja (no fusión)
Por debajo de la fusión sale poco o nada de filamento. El motor paso a paso puede perder pasos. Suba T y baje E rpm hasta ver un flujo continuo. Luego espere 30 a 60 segundos antes del siguiente cambio.

B) Temperatura demasiado alta (patinaje)
Muy por encima de la fusión el material puede patinar en el sinfín: el tornillo gira y sale poco filamento. Baje T y baje E rpm hasta que vuelva el flujo. Espere 30 a 60 segundos entre pasos.

C) Punto óptimo (rendimiento estable)
Cuando E y T están estables, el pull P se asienta a una velocidad bastante constante (ejemplo: P cerca de 25 rpm). Ese P es su caudal actual. Para subirlo (por ejemplo hacia 30), aumente T y E a la vez, midiendo el diámetro para no entrar en patinaje. No salte las dos consignas de un golpe.

Tras cada movimiento espere 30 a 60 segundos, mida a la salida del bobinador y vuelva a ajustar. Cuando esto le salga a mano, vea Cuándo usar el predictor y Subir el rendimiento con Optimizar.

Ver también (no editar): help.tips.first-time, help.tips.use-predictor, help.tips.optimize-yield, help.extruder.predictor

### Cuándo usar el predictor

ID: help.tips.use-predictor Padre: help.tips

Título

Cuándo usar el predictor

Resumen (una línea)

Domine el Manual primero. El predictor actúa con PULL Auto, temperatura en rango y 1,75 mm estable.

Cuerpo

Cuándo usar el predictor - Cuando ya pueda sostener una corrida a mano, y tenga sensor analógico o digital, active el predictor. Es un ayudante, no un sustituto de un fundido que no fluye.

Solo actúa si se cumple todo esto:
- Predictor habilitado (Auto ON).
- PULL Auto (en PULL Manual solo muestra estado).
- Temperatura real suficientemente cerca del objetivo (si no, el panel muestra AG).
- Llegan muestras de diámetro (sensor o un valor Manual que usted cargó).

Antes de activarlo, opere unos minutos en Manual (o con Auto apagado) y compruebe:
- No está en una zona extrema (el material fluye).
- El diámetro ya se acerca a 1,75 mm, con PULL Auto.

Cuando esa foto sea estable, active el predictor y deje que mantenga el diámetro. Deje Optimizar en OFF para producción normal. Vea Subir el rendimiento con Optimizar solo si quiere más caudal.

Ver también (no editar): help.tips.first-time, help.tips.extreme-zones, help.tips.optimize-yield, help.extruder.predictor, help.tips.predictor-codes

### Códigos LCD del predictor (imprimir)

ID: help.tips.predictor-codes Padre: help.tips

Título

Códigos LCD del predictor (imprimir)

Resumen (una línea)

Hoja de referencia AH, AB, AS, AC, AO, AG, AN, AP, AU, AZ, AE±, AT± para pegar en la pared del taller.

Cuerpo

Códigos LCD del predictor — IMPRIMA ESTA PÁGINA. Péguela junto al Smart LCD del MK3.

Con Auto ON, la pantalla principal puede mostrar un token junto a A. Ese es el estado del predictor.

AH Hold tras una corrección. Espere. No toque consignas.
AB Diámetro en banda (cerca del objetivo). Bien. Déjelo.
AS Espera tras un cambio de temperatura. Espere.
AC Sensor sin calibrar. Termine Need Calibrate! (6 filas en FW actual; 3 en el antiguo).
AO Hall apagado (no debería ocurrir en el firmware actual).
AG Aún no puede corregir. INICIE el extrusor, PULL Auto, espere a que T se acerque al objetivo.
AN Sin muestras de diámetro. Revise el sensor o cargue un Ø Manual.
AP Aviso de patinaje. Solo actúa con Optimizar ON.
AU Aviso de no fusión. Solo actúa con Optimizar ON.
AZ Freeze 90 s tras una emergencia. Espere y continúe.
AE+ / AE- Aplicó corrección de E (sinfín) subir / bajar.
AT+ / AT- Aplicó corrección de T subir / bajar.

También: SIN A o - = Auto OFF. A solo = Auto ON, sin cambio este ciclo. M = Manual (no aplica solo).

Si opera solo desde el LCD, esta tabla alcanza para una mirada. El detalle está en Extrusor → Asistente predictivo y en la ayuda de la pantalla principal.

Ver también (no editar): help.mk3.main-screen, help.extruder.predictor, help.tips.use-predictor, help.tips.sensor-calibrate
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

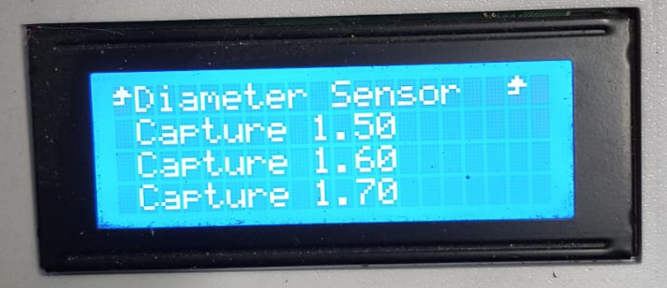
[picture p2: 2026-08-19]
docs/mk3_menu_capture.png

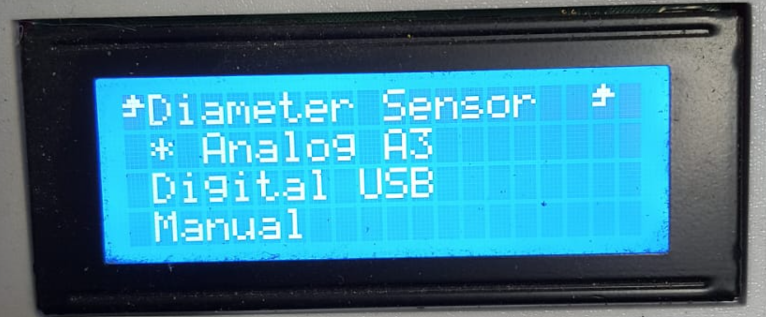
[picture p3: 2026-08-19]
docs/mk3_menu_diameter_sensor.png

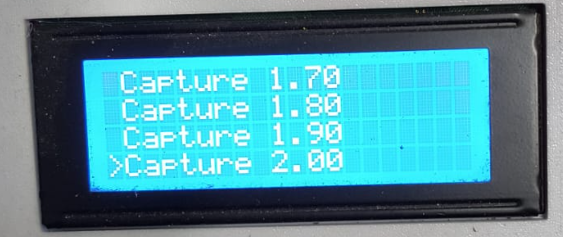
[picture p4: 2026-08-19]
docs/mk3_menu_capture_scroll.png

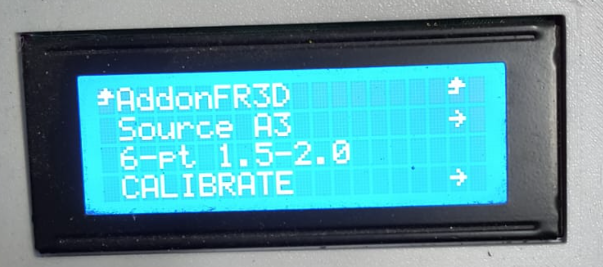
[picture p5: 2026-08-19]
docs/mk3_menu_diameter_sensor_items.png

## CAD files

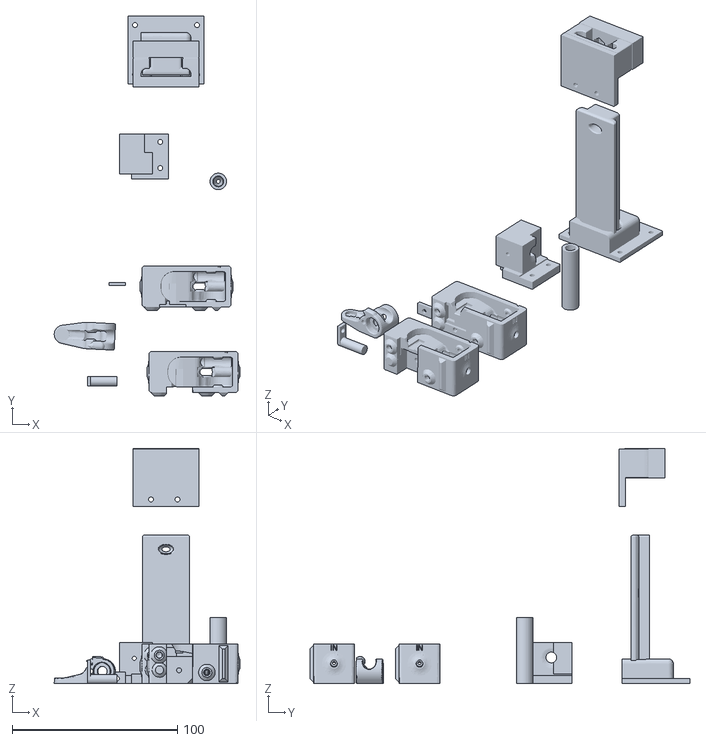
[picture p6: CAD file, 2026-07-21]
docs/diameter_sensor_infidel/Hall_Sensor_Parts.stl
112.2 x 229.7 x 142.3

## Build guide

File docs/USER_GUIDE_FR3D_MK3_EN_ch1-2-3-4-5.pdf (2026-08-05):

### USER GUIDE FR3D MK3 — Chapters 1, 2, 3, 5

Source: `USER GUIDE_FR3D_MK3_EN.pdf` Clean extract for Google Docs / GitHub (standalone MK3S+ understanding). Chapters included: 1, 2, 3, 5 (main screen), 6 (operation recommendations). Chapter 4 omitted. 1. Project objective

Build a filament extrusion and spooling platform with digital control, telemetry and traceability, based on the MK3S+ with FR3D Addon firmware operating in standalone mode from the machine LCD. Documentation scope. This document is directed exclusively at the MK3S+ with FR3D Addon operating in

standalone mode (LCD and onboard firmware control). It does not cover Raspberry Pi gateway pairing or the browser-based operations UI. Diameter sensor hardware. The MK3S+ can use either a Hall-effect diameter sensor (INFIDEL-style printed

assembly, SS495A on pin A3) or an optical diameter sensor based on ARTME 3D. Calibration on the LCD is the same for both. Printed parts for the Hall-effect head: `documnetation/diameter_sensor_infidel/Hall_Sensor_Parts.stl` (multi-body STL — split into individual parts in

the slicer before printing). • Real-time control of the extruder and spooler. • Capture and analysis of process data in real time and in batch mode (CSV formats). • Interface-driven operation with multilingual support (ES/EN). • Architecture ready for further automation and quality improvements. 2. Addon FR3D

- Modified MK3S+ firmware for USB serial communication with the Python core on a Windows PC. • Python core synchronized with USB serial ports and control/telemetry logic for integration

with Addon FR3D - MK3S+. • Structured configuration, event logging, analysis and management in CSV. • Coordinated operation flow with MK3 firmware . • The two main functions are the Caliper and the diameter predictor

2.1 Diameter Meter Caliper
The Caliper is only for calibrating the diameter gauge and ensuring it measures correctly. Calibration is only done once during assembly. Then, the offset is used to adjust the zero point if it's misaligned (as is the case with all calibrators on the market that have a zero adjustment). Specifically, this function is only for calibrating the gauge so that the display shows the actual measurement, where the lower limit is 1.5 mm and the upper limit is 2.5 mm. The gauge will always indicate the actual measured value between 1.5 and 2.5 mm. Outside these limits, it displays 1.5 or 2.5 mm due to a mechanical issue related to the physical sensor. 2.2 Diameter Predictor (FR3D MK3S+)
2.2.1) What is the Predictor? The Diameter Predictor is a closed-loop assistant that runs on the MK3S+ FR3D firmware. It uses the diameter sensor calibrated in the previous step to keep the extruded diameter close to the target (typically 1.75 mm, within the parameters given to the predictor). The predictor stays inactive until calibration is valid (`CALV=1`). Every ~10 seconds, the predictor analyzes the data and, if correction is required and safety conditions are met, the algorithm adjusts:
1) Extruder speed (E): This is the fastest response to diameter errors. 2) Nozzle temperature (T): When RPM alone is insufficient, the predictor switches to a thermal correction strategy. 2.2.2) Correction (Safety Gates) The predictor does not act unless, among other checks: • The predictor is in automatic mode. • The extruder is running (ES = 1). • The current temperature is close to the setpoint (|Tact − Ttgt| ≤ the maximum configured

temperature). • Spolling is set to automatic. • The diameter signal is stable, with no electrical noise (medium debounce: large jumps

require confirmation using Med jump/Med confirm). • The proposed R and T values are maintained within Rmin/Rmax and Tmin/Tmax. (This

determines the minimum and maximum adjustment limits of MK3S+.) • What is the target diameter and what margin of error does it tolerate before taking action?

etc.. 3. Diameter Hardware connection

Sensor options. Hall-effect (INFIDEL-style, SS495A on A3 with EMI filters below) or optical (ARTME 3D). For Hall-effect mechanics, print the nine bodies from `Hall_Sensor_Parts.stl`, assemble with roller/magnet/SS495A, and mount on the filament path before the puller.

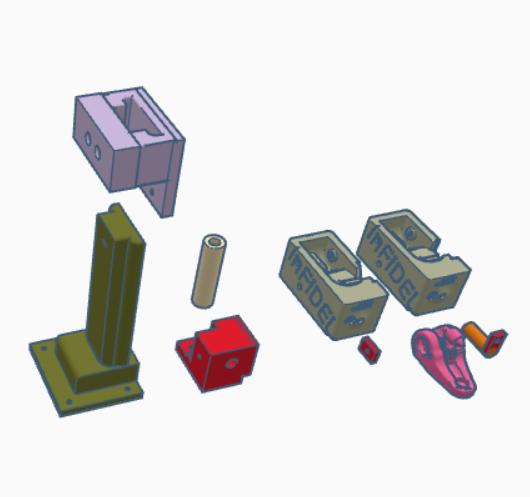
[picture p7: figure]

INFIDEL printed parts

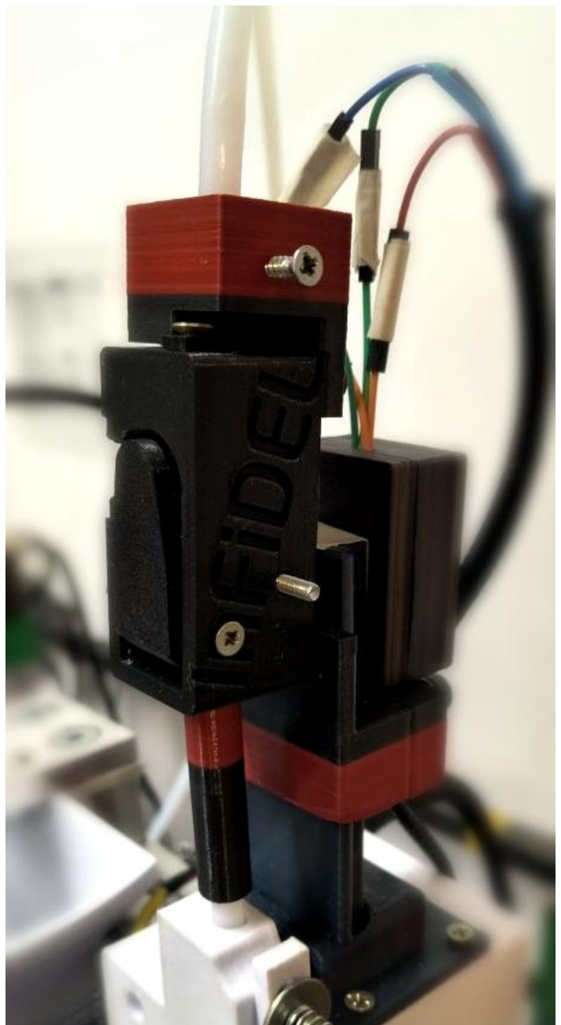
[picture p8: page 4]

INFIDEL assembled on MK3S+ Recommended Technical Note: Noise Reduction Filter for the SS495A (Hall-effect option). To protect the highly

sensitive SS495A linear Hall-effect sensor from high-frequency electromagnetic interference (EMI) caused by stepper motors and heating elements, a two-stage filtering strategy is implemented. This will be done in two stages: one for decoupling the power supply and another RC low-pass filter stage for the analog signal.

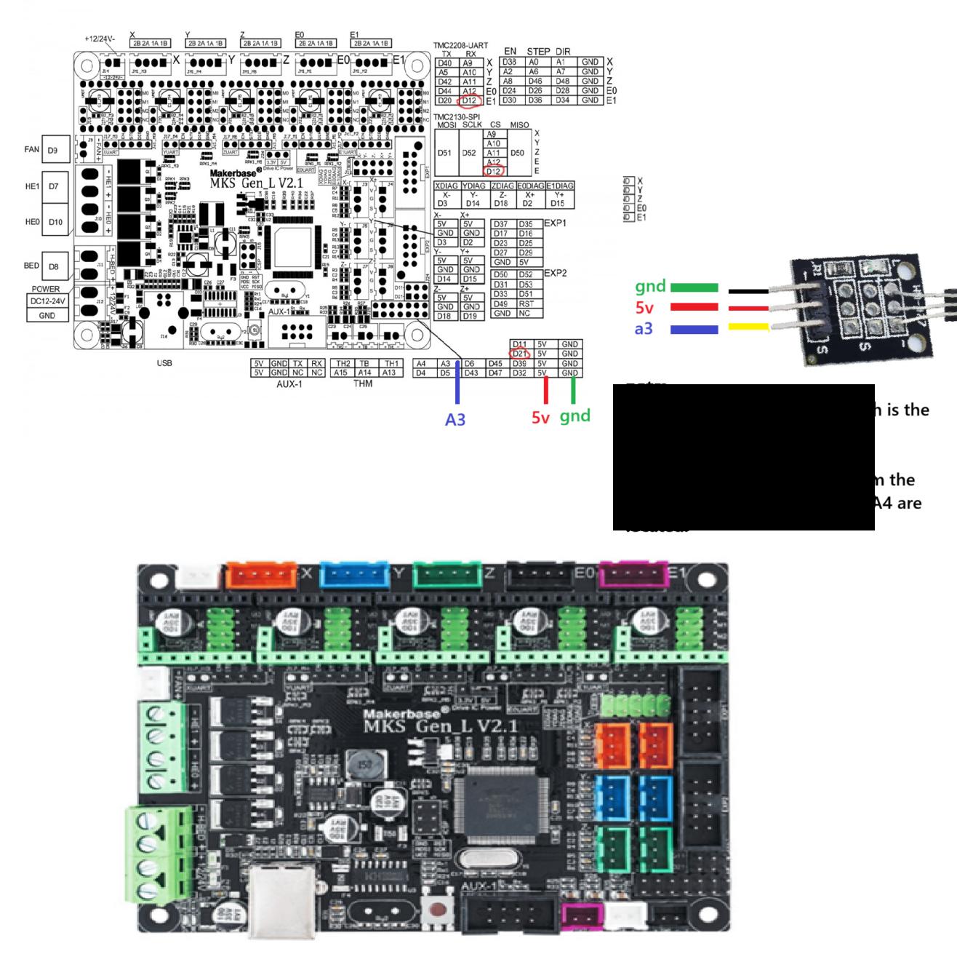
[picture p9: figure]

Figure p5
Stage 1 - Power Supply Decoupling (located 4 cm from the sensor). Components: • One 0.1 µF ceramic capacitor (labeled 104) • One 4.7 µF electrolytic capacitor. Wiring Setup: Connect the positive (+) lead of the 4.7µF electrolytic capacitor (the longer leg) to one leg of the

0.1µF ceramic capacitor. Solder this connection directly to the 5V (Vin) line. Connect the negative (-) lead of the electrolytic capacitor (the shorter leg aligned with the strip on the body) to the remaining leg of the ceramic capacitor. Solder this connection directly to the GND line. Note: The sensor's output (data) wire completely bypasses this block and continues along the line. Stage 2 - Signal Data Filtering (RC Low-Pass Filter): Components: • One 1kΩ resistor • One 10nF ceramic capacitor (labeled 103). Wiring Setup: Resistor Placement: Cut the signal (output) wire coming from the sensor. Solder the incoming

wire to one end of the 1kΩ resistor. Connect the other end of the resistor directly to the microcontroller's analog input pin. Capacitor Placement (Critical): Place the 10nF ceramic capacitor as close as possible to the microcontroller pin (ideally less than 4 cm or directly on the board). Solder one leg of the capacitor to the analog input pin (the same junction where the resistor ends) and the other leg directly to the microcontroller's GND pin. 1. MK3S + FR3D main screen (1) Displays current filament diameter (2) Displays average filament diameter

(from the last 10 seconds - with 20 samples) (3) Displays prediction mode: A = automatic adjustment, M = manual adjustment

5.1 Configuration
You can configure from the Python / web console or from the MK3 LCD: Control → AddonFR3D. #### 5.1.2 Diameter Sensor (LCD)

Path: Menu → Control → AddonFR3D → Diameter Sensor

Menu item | Role
Pattern Diameter | Shows Now (active mm preset) and Set for the *other* preset only
Need Calibrate! | Only when calibration is incomplete (`CALV=0`). Opens the Capture list
CALIBRATE | Only when calibrated (`CALV=1`). Contains Capture Lo / Mid / Hi
Offset | Fine diameter compensation (DOFF), typically −0.20…0.20 mm
Presets (Pattern Diameter)
Preset | Lo / Mid / Hi (mm)
Wide (A) | 1.5 / 1.7 / 2.0
Standard (B, factory default) | 1.7 / 1.75 / 2.0
Changing pattern with Set:
2. Invalidates calibration (`CALV=0`) and clears the three Capture points. 3. Sets OFFSET (DOFF) to 0 (does not carry over bias from the previous preset). 4. Shows New Setting OK / Need Calibrate!!! / Click To calibrate — click opens Capture for the first point. #### 5.1.2.1 Diameter meter calibration (Capture)

Use physical calibration patterns that match the active preset labels on the LCD. 5. Open Need Calibrate! or CALIBRATE. 6. Place the matching physical pattern under the diameter sensor.

7. Select the Capture row (e.g. Capture 1.75 or Capture 1.50 depending on preset). 8. Wait at least 5 seconds for a stable ADC reading. 9. Click the encoder to save. Repeat for all three points until `CALV=1`.

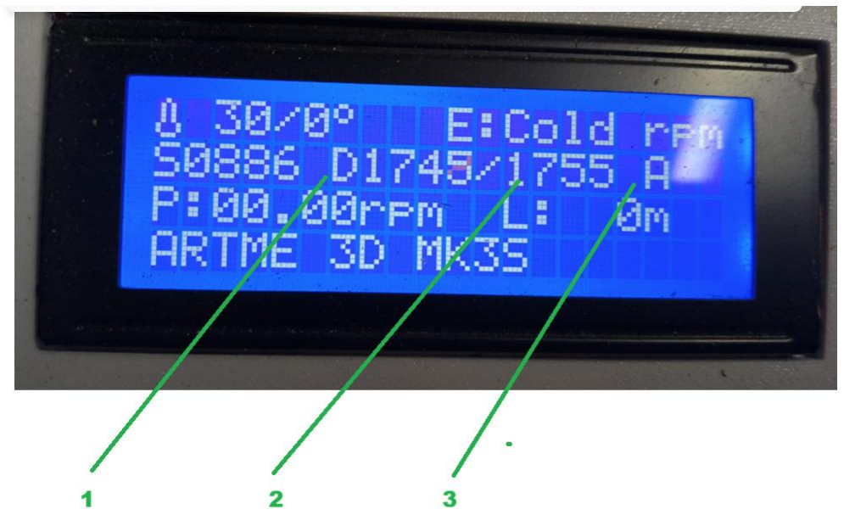
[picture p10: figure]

Figure p8
#### 5.1.2.2 Calibration verification

10. Place a known mid pattern (e.g. 1.75 mm when on the standard preset) under the diameter sensor. 11. Wait at least 15 seconds and return to the main screen. 12. On the second LCD row you see `DXXXX/YYYY` (instant / average ×1000). For 1.75 mm expect about 1750. #### 5.1.2.3 OFFSET compensation

If the screen shows e.g. 1720 instead of 1750:
13. Go to AddonFR3D → Diameter Sensor → Offset. 14. Apply the difference (example: 1750 − 1720 → 0.030 mm) and click to store. 15. Confirm the main screen reads near `D1750/1750`. Note: After a Pattern Diameter → Set change, Offset is reset to 0; recalibrate the three Captures before tuning

Offset again. LCD screenshots — Diameter Sensor menus:

Diameter Sensor (Pattern Diameter / CALIBRATE / Offset) and Control → Diameter Sensor:

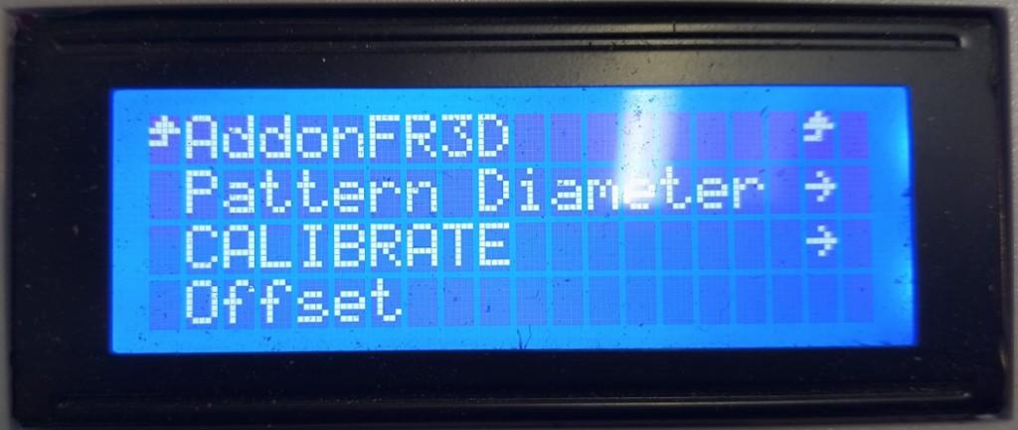
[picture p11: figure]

Figure p10

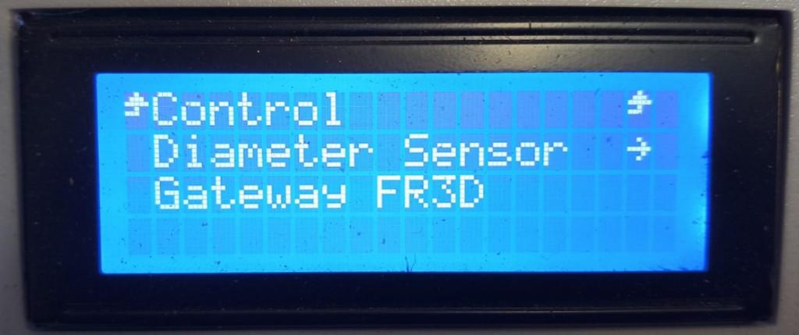
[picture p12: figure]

Figure p10
When calibration is incomplete (`CALV=0`), the middle item is Need Calibrate! instead of CALIBRATE (simulated LCD — same layout as a live panel):

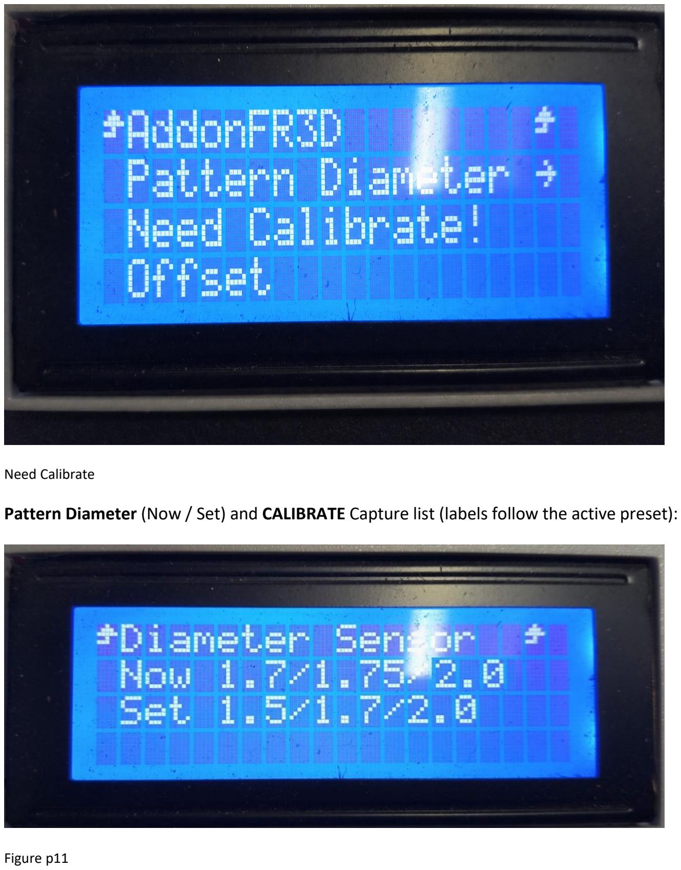
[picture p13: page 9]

Need Calibrate Pattern Diameter (Now / Set) and CALIBRATE Capture list (labels follow the active preset):

Figure p11

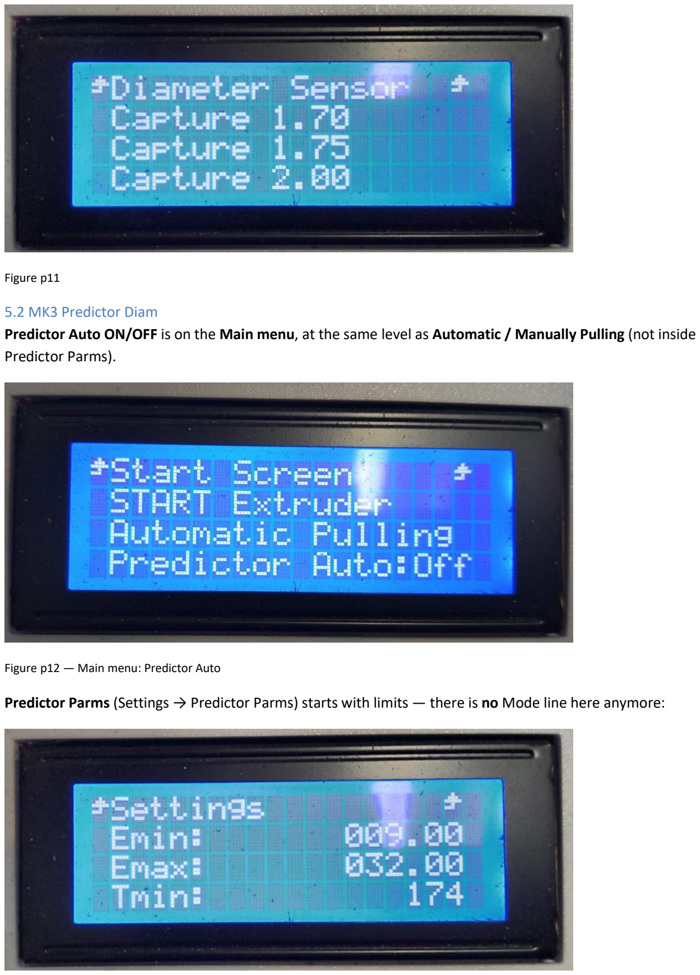
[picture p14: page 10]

Figure p11
5.2 MK3 Predictor Diam
Predictor Auto ON/OFF is on the Main menu, at the same level as Automatic / Manually Pulling (not inside Predictor Parms).

Figure p12 — Main menu: Predictor Auto Predictor Parms (Settings → Predictor Parms) starts with limits — there is no Mode line here anymore:

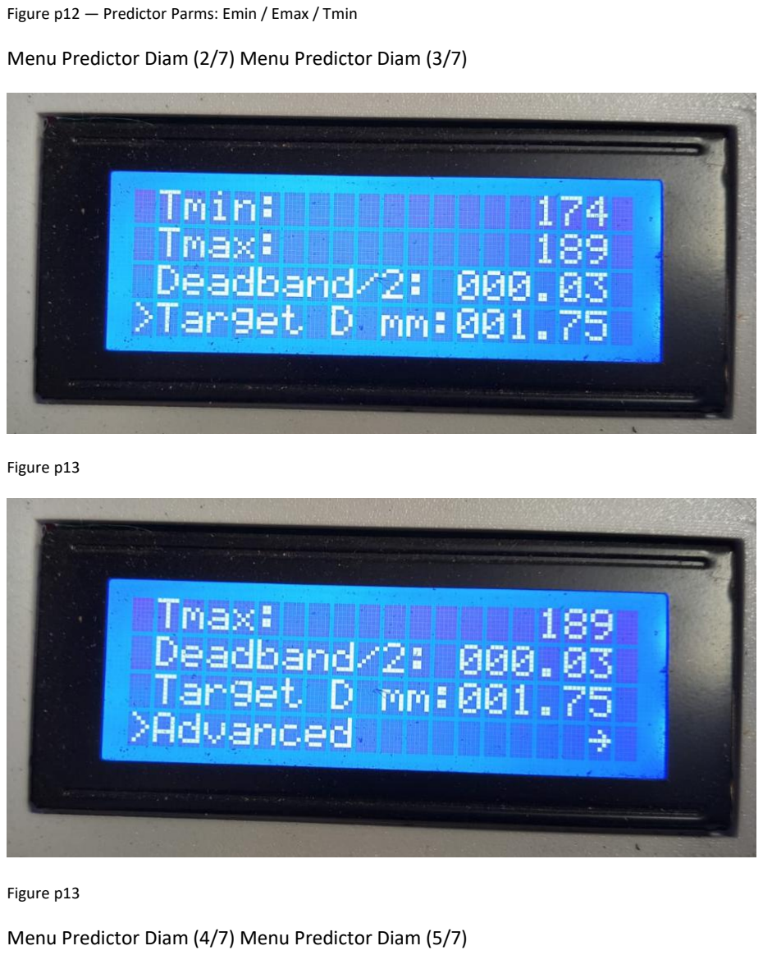
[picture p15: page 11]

Figure p12 — Predictor Parms: Emin / Emax / Tmin Menu Predictor Diam (2/7) Menu Predictor Diam (3/7)

Figure p13

Figure p13
Menu Predictor Diam (4/7) Menu Predictor Diam (5/7)

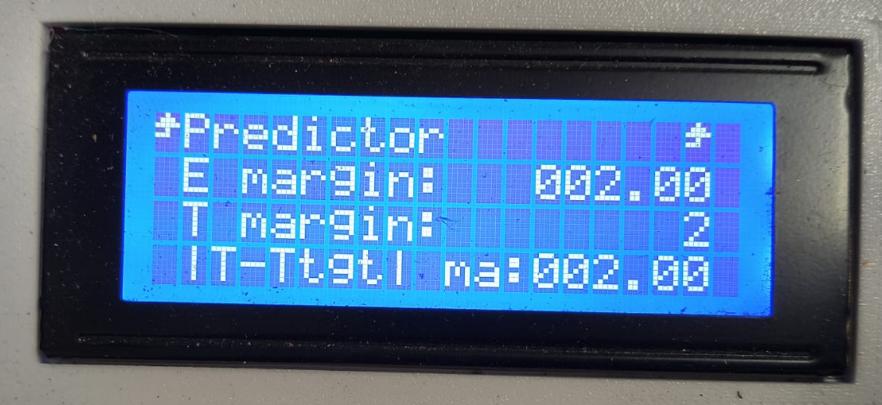
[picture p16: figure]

Figure p14

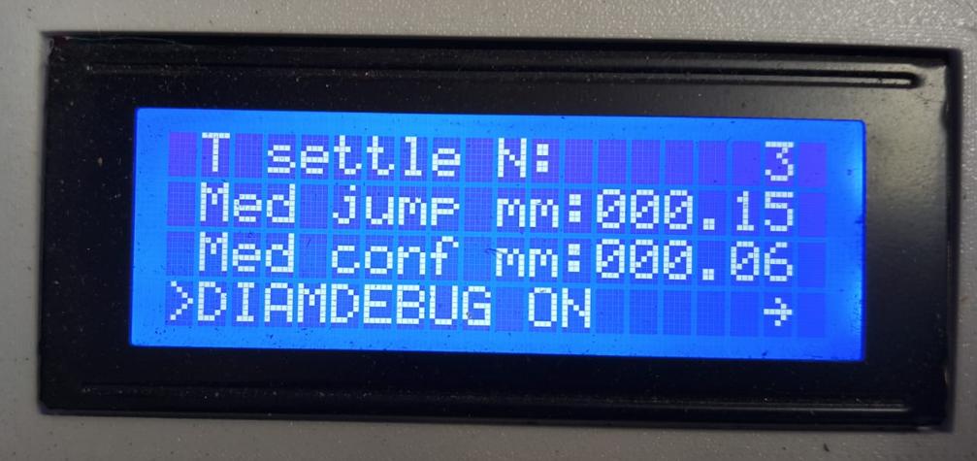
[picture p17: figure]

Figure p14
Menu Predictor Diam (6/7) Menu Predictor Diam (7/7) Predictor Auto — On the Main menu (same level as Automatic / Manually Pulling): ON applies real-time corrections within configured limits; OFF computes/suggests only (status letter A / M on the home screen). Emin — Lower RPM limit allowed for extrusion-speed corrections. Prevents the predictor from reducing speed too much and compromising flow continuity. Emax — Upper RPM limit allowed for speed corrections. Prevents over-acceleration and saturation- driven oscillations in the extruder. Tmin — Lower thermal limit of the assistant working range (it does not

change the base RTF setpoint by itself). Used to bound temperature correction decisions.

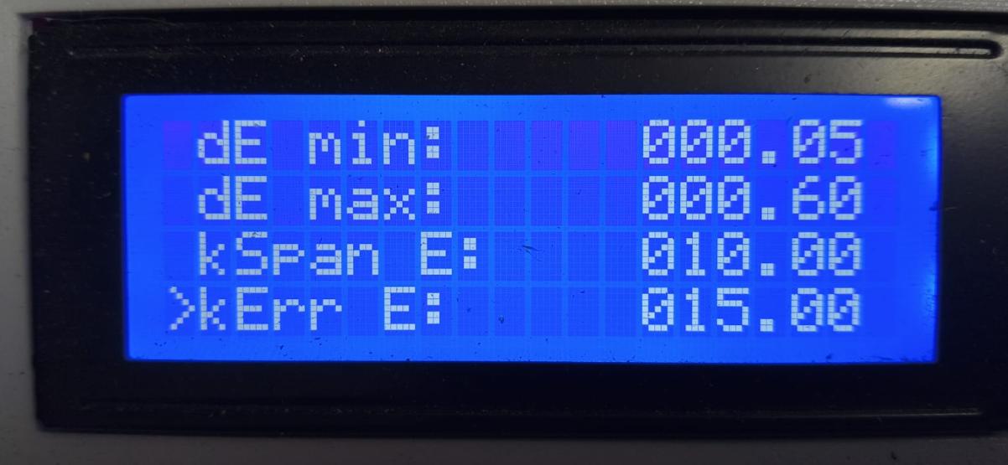
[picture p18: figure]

Figure p15

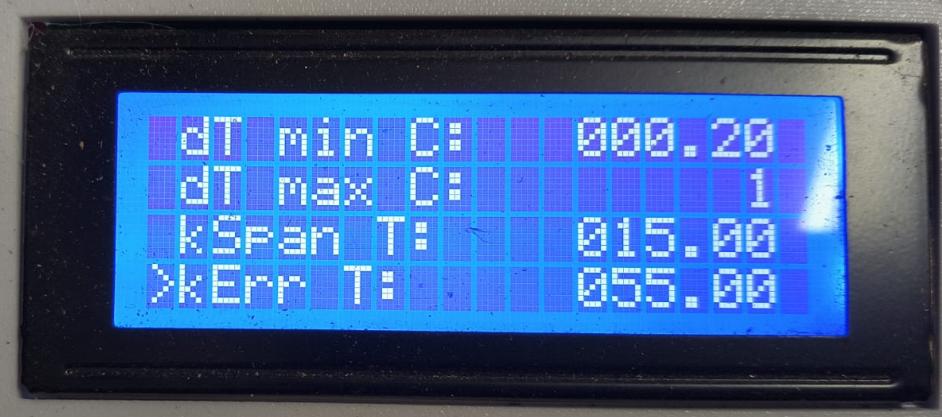
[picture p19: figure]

Figure p15
Tmax — Upper thermal limit of the assistant range. Keeps corrections inside a safe zone for material/process. Deadband/2 mm — Half of the deadband around target diameter. If diameter stays within target ± band, predictor does not correct. Larger bands = fewer corrections; smaller bands = more sensitivity. Target D mm: —

Target filament diameter the system tries to maintain. All adjustment and deadband logic is computed against this value. =====Advanced===== Advanced-Wait after T change — Number of cycles/fusions the predictor waits after applying a temperature change before correcting T again. Reduces thermal-inertia rebound. Advanced-E margin to switch to T (rpm) — Hysteresis that authorizes transition from RPM correction to

temperature correction. Avoids overly frequent strategy switching. Advanced-T margin to switch to R (°C) — Hysteresis to return from T correction to R correction. Improves switching stability between channels. Advanced-|Tact−Ttgt| max °C — Maximum allowed difference between actual and target temperature to

enable predictive correction. If exceeded, the predictor is inhibited to avoid correcting in unstable conditions. Advanced-T settle N— Predictor window (number of samples per cycle). Higher N filters noise and stabilizes;

lower N speeds up corrections but may overfit. Suggested starting point: N=3. Advanced-CYCLE — CYCLE — Telemetry and predictor cycle period, in seconds. Allowed values: 5 or 10 (default 10). Defines how often the MK3 closes a sampling window and performs a diameter predictor evaluation. With 10 s, the system filters noise better and corrections are more stable. With 5 s, it reacts faster to diameter changes, at the cost of greater sensitivity to sudden variations. Advanced-Med jump mm (DIAMJDB) — How much the ~10 s rolling median diameter must change versus the last published median to treat it as a “large jump” that is NOT applied immediately; the MK3 keeps the previous published median while awaiting confirmation in the
following window before updating predictor logic and CSV. Higher values tolerate transients better (e.g. inserting/cutting filament); lower values react faster but trigger debounce more often. It does not fix systematic sensor calibration — use DOFF / diameter-sensor Offset for bias. Advanced-Med confirm mm (DIAMJPM) — After a pending large jump crosses “Med jump”, firmware requires that the raw median of the next window matches the pending candidate within ± this tolerance (absolute) before publishing; otherwise the hold can continue/reject. It is the confirmation slack between successive windows: higher accepts more easily; lower demands a cleaner match. Advanced-DIAMDEBUG — MK3 CSV format only: appends lightweight diagnostic columns to see FIFO floor rejects (corr_drop_n), median debounce holding (corr_jump_hold, jump_pending_mm), and raw vs accepted FIFO fill (fifo_n_raw / fifo_n_used). Handy during tuning; commonly OFF during normal runs for shorter rows. Does not alter predictor correction logic. The CSV is send to Python control to process. Advanced-dE min — Minimum RPM correction step per cycle when acting on R. Prevents corrections that are too small to have practical effect. Advanced-dE max — Maximum RPM correction step per cycle. Limits abrupt changes to avoid mechanical/flow instability. Advanced-kSpan E — E gain associated with distance to the diameter band (span component). Higher values respond more strongly when outside band. Advanced-kErr E — E gain associated with absolute diameter error (error component). Increasing it speeds R

correction, but can induce overshoot. Advanced-dT min C — Desired/base thermal change per cycle when channel T decides to act. Represents the minimum thermal correction intent. Advanced-dT max C — Maximum allowed temperature change per correction/cycle. In practice: applied dT = min(desired dT, max dT). Keep low (e.g., 1 °C) due to thermal inertia. Advanced-kSpan T — Thermal gain by distance to band (span component of T channel). Advanced-kErr T — Thermal gain by diameter error (error component of T channel). High values correct faster but may cause thermal oscillation. #### 5.2.1 Recommended Settings

Predictor ON/OFF Diamdebug: ON
Modo Manual/autiomatic Traget Diam: 1.75 Deadband/2: 0.03 Med Salto m: 0.15 Med conf mm:0.06 Tem match: 2 E min:9 E max: 32 T min :174 Tmax:189 CYCLE: 10 dE min: 0.05 dE max:0.6 kSpan E: 10 kErr E:15 dT min:0.2 dT max:1 kSpan T:15 kErr T:55 E margin: 2 T margin: 2 T settle N: 3 Window N: 3
6. Operation recommendations

Objectives
Steps and recommendations for extrusion with automatic predictive diameter control (MK3S+ FR3D Addon, standalone LCD). Step 1 — Prepare (Predictor Auto OFF) • Set Predictor Auto: OFF. • Review diameter-sensor calibration (Pattern Diameter / CALIBRATE on LCD; Hall-effect INFIDEL or ARTME

3D optical). • Place shredded material in the hopper. • Make sure the material is dry.

Step 2 — Base setpoints
Go to Settings and assign: • Temperature
- Extruder RPM
- Fan
Step 3 — Start extrusion
Once the target temperature is reached, start extrusion. Step 4 — Thread and enable pulling

Thread the extruded filament and set Pulling (spooler) to Automatic. Step 5 — Enable Predictor Auto

When automatic pulling is stable and the diameter on the LCD is close to the target (shown as `Dxxxx` / average), set Predictor Auto: ON. From this point, the prediction algorithm applies automatic diameter corrections each operating cycle. Step 6 — Predictor reaches temperature / RPM limits

If the predictor saturates against its configured temperature and RPM limits (`Tmin`/`Tmax`, `Emin`/`Emax`), stop relying on further predictive corrections and apply the operator tips below (from in-app Help: Tips &

tricks). #### Filament too thin

When average diameter (`Dprom`) is below the acceptable window, work through these steps in order:
16. Nozzle FAN — Manually increase nozzle fan speed (F) so the filament stretches less under tension before

solidifying. 17. Mechanical distance adjustment — Manually decrease the physical sensor distance (S), moving it closer to

the nozzle to give the molten plastic less stretch time. 18. Physical check and calibration — Inspect internal wear of the nozzle orifice. Verify the diameter sensor is

calibrated and not reporting false readings. 19. Batch recipe adjustment — Decrease recycled material percentage (−T%) and increase virgin material

percentage (+V%) to reduce melt fluidity. #### Filament too thick

When average diameter (`Dprom`) is above the acceptable window, work through these steps in order:
20. Nozzle FAN — Manually reduce nozzle fan speed (F) so the filament can stretch under tension before

solidifying. 21. Mechanical distance adjustment — Manually increase the physical sensor distance (S), moving it away

from the nozzle to give the molten plastic more stretch time. 22. Physical check and calibration — Inspect internal wear of the nozzle orifice. Verify the diameter sensor is

calibrated and not reporting false readings.

23. Batch recipe adjustment — Increase recycled material percentage (+T%) and decrease virgin material percentage (−V%) to increase melt fluidity.

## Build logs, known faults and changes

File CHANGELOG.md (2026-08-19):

# Changelog — MK3 → MK3 + FR3D Addon

History of meaningful firmware changes relative to the original Desktop Filament Extruder **MK3** (Mackerel) baseline published as tag `v-mk3-original`.

## [gateway-v2.4.15] — 2026-08-18

### MK3 firmware (EEPROM V32) + gateway program (Pi OTA + Windows)

- Release tag [`gateway-v2.4.15`](https://github.com/dadonec-boop/MK3-FR3D-Addon/releases/tag/gateway-v2.4.15): Pi OTA zip, Windows x64 zip, MK3 firmware zip
- Analog A3 Hall calibration is now **one 6-point pattern**: 1.50, 1.60, 1.70, 1.80, 1.90, 2.00 mm (no Pattern A/B). LCD: **6-pt 1.5-2.0** + Capture 1.50…2.00
- `CALV=1` only if the six ADC values are distinct and monotonic. Flashing V32 **resets** a previous 3-point Hall cal
- Gateway / web app: if the Mega still has old firmware (no `CALN,6`), the UI keeps Pattern A/B (3 points). USB Digital and Manual Ø are unchanged
- OTA swap **preserves** `fr3d_web` (avoids nginx 500 after update). Also in this zip vs 2.4.13: USB Ø bar uses HOSTD; CONFIG sensor source (A3/USB/Manual) single-click
- Web app **2.0.35**: in-app help (EN/ES/DE) updated for 6-point cal; live catalog at [fr3d-addon.web.app](https://fr3d-addon.web.app/)
- In-app help review export: [`docs/ayuda_fr3d_es_revision.docx`](docs/ayuda_fr3d_es_revision.docx)
- Update Pi with CONSOLE `PI UPDATE GATEWAY latest` — **does not replace the SD factory image**
- **Reflash the MK3 board** to use 6-point LCD calibration

## [gateway-v2.4.13] — 2026-08-18

### Gateway program (Pi OTA only)

- Release tag [`gateway-v2.4.13`](https://github.com/dadonec-boop/MK3-FR3D-Addon/releases/tag/gateway-v2.4.13): Pi OTA zip (`fr3d-gateway-*.zip`, `MANIFEST.json`)
- Same gateway Python as **2.4.12**; version bump to exercise **PI UPDATE GATEWAY latest** from the web app (paired with Firebase UI **2.0.34**)
- Web app fixes (Firebase deploy, not in this zip): Digital USB diameter bar fallback (`HOSTD`), CONFIG sensor source (A3/USB/Manual) single-click
- Update Pi with CONSOLE `PI UPDATE GATEWAY latest` or the startup Yes/No prompt — **does not replace the SD factory image**

## [gateway-v2.4.12] — 2026-08-17

### Gateway program (Pi OTA + Windows) and MK3 firmware

- Release tag [`gateway-v2.4.12`](https://github.com/dadonec-boop/MK3-FR3D-Addon/releases/tag/gateway-v2.4.12): Pi OTA zip, Windows x64 zip, MK3 firmware zip
- Manual Ø range **1.20–2.80 mm** (LCD `D mm`, host `DIAMSET`, web Manual bar). Hall Analog A3 stays 1.50–2.20 mm
- Apply Target D no longer overwritten by a stale QUERY after PRED APPLY
- Web app **2.0.34**: Tips & tricks — two-pass homogenization of the grind; colour recipes on light-grey grind
- Web app help (106 topics, EN/ES/DE at [fr3d-addon.web.app](https://fr3d-addon.web.app/)): quick start (Standalone / LAN / FULL Cloud), **system architecture note** (firmware keeps the feedback loop; gateway handles monitoring), LCD predictor cheat sheet, sensor calibration troubleshooting, when to use **Optimizar P\***, masterbatch **>5%** warning, two-pass recipe limits
- In-app help review export: [`docs/ayuda_fr3d_es_revision.docx`](docs/ayuda_fr3d_es_revision.docx)
- Update Pi with CONSOLE `PI UPDATE GATEWAY latest` (does not replace the SD factory image)
- **Reflash the MK3 board** to use LCD / DIAMSET up to 2.80 mm

## [gateway-v2.4.11] — 2026-08-16

### Gateway program (Pi OTA + Windows)

- Release tag [`gateway-v2.4.11`](https://github.com/dadonec-boop/MK3-FR3D-Addon/releases/tag/gateway-v2.4.11): Pi OTA zip, Windows x64 zip, MK3 firmware zip
- Web app 2.0.31: pairing/login opens the FR3dAddon product-family WIKI; pairing can return to sign-in without a token
- Update Pi with CONSOLE `PI UPDATE GATEWAY latest` (does not replace the SD factory image)

## [gateway-v2.4.10] — 2026-08-15

### Gateway program (Pi OTA + Windows)

- Release tag [`gateway-v2.4.10`](https://github.com/dadonec-boop/MK3-FR3D-Addon/releases/tag/gateway-v2.4.10): Pi OTA zip, Windows x64 zip, MK3 firmware zip
- Older MK3 firmware stays usable: Analog A3, extrusion, winder and predictor Auto
- USB/Manual, Optimizar and P* only if MK3 QUERY reports `DIAMSRC` / `PREDOPT` / `PREDPSTAR`
- Update Pi with CONSOLE `PI UPDATE GATEWAY latest` (does not replace the SD factory image)

## [gateway-v2.4.9] — 2026-08-15

### Gateway program (Pi OTA + Windows)

- Release tag [`gateway-v2.4.9`](https://github.com/dadonec-boop/MK3-FR3D-Addon/releases/tag/gateway-v2.4.9): Pi OTA zip, Windows x64 zip, MK3 firmware zip
- Aligns with MK3 **Optimizar P\*** (E+T, puller stays Auto)
- Same web app for **internet** and **LAN / WiFi** (with or without internet)
- Update Pi with CONSOLE `PI UPDATE GATEWAY latest` (does not replace the SD factory image)

## [v-mk3-fr3d] — 2026-08-15

### Predictor Optimizar P*

- **Optimizar** drives **P\*** by acting on **E+T**; puller stays in **Auto** (never writes P Manual)
- Soft Ø band slack while optimizing; E→P health uses a longer persist window
- `dist/MK3-FR3D-Addon.zip` refreshed (15 Aug 2026). **Reflash the MK3 board** to use this Optimizar behaviour.

## [v-mk3-fr3d] — 2026-08-13

### Diameter sensor sources (exclusive)

- `DIAMSRC` / LCD **Source**: **Analog A3** XOR **Digital USB (BDWidth host)** XOR **Manual (mock)**
- Manual Ø from LCD (`D mm`) or host; QUERY reports source for web CONFIG / predictor
- Older boards without `DIAMSRC` keep Analog A3 only
- `dist/MK3-FR3D-Addon.zip` refreshed (13 Aug 2026). **Reflash the MK3 board** to use USB/Manual sources.

## [gateway-v2.4.1] — 2026-08-13

### Gateway program (Pi OTA + Windows)

- Release tag [`gateway-v2.4.1`](https://github.com/dadonec-boop/MK3-FR3D-Addon/releases/tag/gateway-v2.4.1): Pi OTA zip, Windows x64 zip, MK3 firmware zip
- Pi: LAN Flutter UI + local `/api` alongside Firebase; BDWidth USB path; reject USB/Manual on legacy MK3
- Update Pi with CONSOLE `PI UPDATE GATEWAY latest` (does not replace the SD factory image)

## [v-mk3-fr3d] — 2026-08-04

### Predictor UI / Hall diameter

- LCD / host state tokens: `SIN A`, `A`, `AH`, `AB`, `AS`, `AC`, `AO`, `AG`, `AN`, `AE±`, `AT±` (`PREDUI` in QUERY)
- `AC` = calibration invalid (`CALV=0`); `AO` = Hall off (`DH=0`) — no longer shared as one code
- Hall diameter path **always ON** (`DH=1` default; `DH0` ignored; EEPROM load forces ON)
- QUERY reports real `DH`; `CALV1` reactivates saved cal and enables Hall
- `dist/MK3-FR3D-Addon.zip` refreshed (4 Aug 2026)

## [pi-gateway-v0.8] — 2026-08-13

### Pi Zero 2 W factory image (Release asset)

- Published [`fr3daddon-v0.8-small.img.zst`](https://github.com/dadonec-boop/MK3-FR3D-Addon/releases/download/pi-gateway-v0.8/fr3daddon-v0.8-small.img.zst)
- Includes gateway **2.4.1**: LAN Flutter UI (nginx), BDWidth USB path, DIAMSRC sensor modes support
- Release notes: [`pi-gateway-v0.8`](https://github.com/dadonec-boop/MK3-FR3D-Addon/releases/tag/pi-gateway-v0.8)

## [pi-gateway-v0.7] — 2026-08-04

### Pi Zero 2 W factory image (Release asset)

- Published [`fr3daddon-v0.7-small.img.zst`](https://github.com/dadonec-boop/MK3-FR3D-Addon/releases/download/pi-gateway-v0.7/fr3daddon-v0.7-small.img.zst)
- Release notes: [`pi-gateway-v0.7`](https://github.com/dadonec-boop/MK3-FR3D-Addon/releases/tag/pi-gateway-v0.7)

## [v-mk3-fr3d] — 2026-07-31

### Serial temperature limit (host `T` / `RTFP`)

- Replaced the fixed USB serial ceiling (**190 °C**, later briefly **210**) with a **dynamic** cap driven by predictor **Tmax**:
  - `serial_T_max = max(190, predictor_Tmax + 5)`
  - hard safety clamp: `HEATER_0_MAXTEMP − 15` (~260 °C)
- Raising **Tmax** in Predictor Parms / `PREDTRNG` (LCD or web app) therefore raises the allowed host setpoint automatically (e.g. Tmax **194** → serial up to **199 °C**; PETG Tmax **250** → up to **255 °C** within heater margin).
- Compact HELP text for `T` updated to `0..(Tmax pred+5)`.
- `dist/MK3-FR3D-Addon.zip` refreshed (31 Jul 2026). **Reflash the MK3 board** to apply.

## [pi-gateway-v0.5] — 2026-07-25

### Pi Zero 2 W factory image (Release asset)

- Published [`fr3daddon-v0.5-small.img.zst`](https://github.com/dadonec-boop/MK3-FR3D-Addon/releases/download/pi-gateway-v0.5/fr3daddon-v0.5-small.img.zst)
- Release notes: [`pi-gateway-v0.5`](https://github.com/dadonec-boop/MK3-FR3D-Addon/releases/tag/pi-gateway-v0.5)
- Image includes gateway program **2.0.3** with OTA (`PI UPDATE GATEWAY latest`)

## [v-mk3-fr3d] — 2026-07-23

### Predictor / host USB

- Internal fusion cycle fixed at **2 s** (LCD selector 5/10 s removed; legacy values coerced to 2 s)
- USB CSV emission **on demand** (`CSVQ`); no periodic CSV push over USB
- **T settle** clamped to **15–20** fusions (default 15)
- Transport **hold** after E/T corrective: hold meters + timeout (`PREDHOLDM` / `PREDHOLDT`, LCD Advanced)
- EEPROM schema **V30** (migrate V29 → V30 for hold m/timeout; V28 and earlier paths retained)
- `dist/MK3-FR3D-Addon.zip` refreshed (23 Jul 2026)

## [v-mk3-fr3d] — 2026-07-21

### Diameter sensor (LCD / Pattern Diameter)

- Menu **Control → AddonFR3D → Diameter Sensor**
- **Pattern Diameter**: shows **Now** (active mm preset) and **Set** for the *other* preset only
  - Wide preset **1.5 / 1.7 / 2.0** mm
  - Standard preset **1.7 / 1.75 / 1.8** mm
- Changing pattern: invalidates calibration (`CALV=0`), clears capture mask/ADC points, and resets **Offset (DOFF) to 0**
- After **Set**: confirm screen → first Capture; **Need Calibrate!** when `CALV=0`; **CALIBRATE** when `CALV=1`
- User guide PDF and `dist/MK3-FR3D-Addon.zip` refreshed (21 Jul 2026)
- Printable INFIDEL-style Hall parts: [`docs/diameter_sensor_infidel/`](docs/diameter_sensor_infidel/)

## [v-mk3-fr3d] — 2026-07-14

### Identity / licensing header

- Firmware header notes **FR3D Addon** modifications by **Claudio Dadone** (14 Jul 2026), diameter measurement and predictive diameter control (manual/auto), and http://fr3d-addon.web.app/
- Firmware is prepared for optional remote control via Raspberry Pi Zero 2 W + web app; that host stack is **not** included in this public firmware repository

### Diameter measurement (Hall)

- Hall diameter sensing support (enable flag, ADC calibration points, diameter offset)
- LCD helpers for capture / offset under AddonFR3D-related menus
- Default: Hall diameter **OFF** until calibrated/enabled
- Jump debounce / pending-match filtering for published diameter (CSV / predictor)

### Predictor (diameter control)

- Predictor model integrated in firmware (shared with host/app conventions)
- Modes:
  - **Predictor Auto Off** (`fr3d_pred_mode = 0`): computes / suggests, does **not** auto-apply E/T
  - **Predictor Auto On** (`fr3d_pred_mode = 1`): applies extruder RPM + temperature adjustments in firmware
- Main LCD menu: **Predictor Auto** On/Off toggle (full word “Predictor”)
- Status line mode indicator: `A` = Auto On, `-` = Auto Off
- **Predictor Parms** submenu under Settings (limits, deadband, target D, gains, Advanced)
- Advanced menu includes E/T margins, `|T−Ttgt| max`, settle, CSV cycle 5/10 s, median jump/conf, delta/gains, **DIAMDEBUG** at end (default OFF)

### Predictor defaults (when EEPROM has no FR3D values / `Config_ResetDefault`)

| Parameter | Default |
|---|---|
| Predictor enabled (internal) | ON |
| Predictor Auto | OFF |
| Target D | 1.75 mm |
| Deadband/2 | 0.035 mm (3 decimals on LCD) |
| \|T−Ttgt\| max | 2 °C (integer edit) |
| Emin / Emax | 14 / 26 RPM |
| Tmin / Tmax | 173 / 182 °C |
| E margin / T margin | 2 / 2 (integers on LCD) |
| CSV cycle | 10 s |
| DIAMDEBUG | OFF |
| Hall diameter | OFF |
| Preheat Extruder | 150 °C |

### LCD / Settings UX

- Removed from Settings menu: **Filtra ok USB**, **Grabar settings**, **Cargar settings**
- USB “ok” filtering forced **always ON** (no user toggle; ignores turning it off via EEPROM/`MF`)
- Predictor mode selector removed from Settings (only on main menu as Auto On/Off)
- Fix: returning from Predictor Parms to Settings no longer shows a blank LCD until encoder move

### Host / USB / CSV

- Compact USB command set for predictor, diameter, materials/settings helpers (FR3D protocol)
- CSV telemetry cycle selectable 5 s / 10 s
- Optional DIAMDEBUG CSV diagnostics (default off)

### EEPROM

- Schema evolved through FR3D versions; current store/retrieve version **V28**
- Migration paths from known intermediate versions (V15–V27) where applicable
- Unknown / stock non-FR3D EEPROM → hardcoded defaults via `Config_ResetDefault()`

### Files added versus original MK3 (high level)

- `fr3d_telemetry.cpp` / `fr3d_telemetry.h`
- `fr3d_gateway_id.cpp` / `fr3d_gateway_id.h`
- Related hooks in `MK3_main.cpp`, `ultralcd.cpp`, `Configuration.h`, `ConfigurationStore.cpp`, `temperature.*`, etc.

---

## [v-mk3-original]

Unmodified **Desktop Filament Extruder MK3** firmware tree as archived locally (Mackerel / Marlin-based), without FR3D Addon features.

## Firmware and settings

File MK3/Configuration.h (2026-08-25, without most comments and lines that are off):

#define CONFIGURATION_H
#define STRING_VERSION_CONFIG_H __DATE__ " " __TIME__ // build date and time
#define STRING_CONFIG_H_AUTHOR "(none, default config)" // Who made the changes.
#define SERIAL_PORT 0
#define BAUDRATE 250000
#define FR3D_SERIAL_HOST_DISABLE_GM
#define FR3D_SERIAL_RPM_MIN 0.0f
#define FR3D_SERIAL_RPM_MAX 40.0f
#define FR3D_SERIAL_TEMP_MIN 0
#define FR3D_SERIAL_TEMP_MAX_FLOOR 190
#define FR3D_SERIAL_TEMP_MAX FR3D_SERIAL_TEMP_MAX_FLOOR
#define FR3D_SERIAL_FAN_MIN 0
#define FR3D_SERIAL_FAN_MAX 100
#define DEFAULT_FR3D_SERIAL_FILTER_MSGS_ON true
#define FR3D_CSV_TELEMETRY
#define SINFIN_COMP_ALTA 0
#define SINFIN_COMP_BAJA 1
#define DEFAULT_SINFIN_COMPRESSION SINFIN_COMP_ALTA
#define MOTHERBOARD 34  //FMM only works for this motherboard currently
#define EXTRUDERS 1
#define POWER_SUPPLY 1
#define TEMP_SENSOR_0 1
#define TEMP_SENSOR_1 0
#define TEMP_SENSOR_2 0
#define TEMP_SENSOR_BED 0
#define MAX_REDUNDANT_TEMP_SENSOR_DIFF 10
#define TEMP_RESIDENCY_TIME 30  // (seconds)
#define TEMP_HYSTERESIS 2       // (degC) range of +/- temperatures considered "close" to the target one
#define TEMP_WINDOW     1       // (degC) Window around target to start the residency timer x degC early.
#define HEATER_0_MINTEMP 5
#define HEATER_1_MINTEMP 5
#define HEATER_2_MINTEMP 5
#define BED_MINTEMP 5
#define HEATER_0_MAXTEMP 275
#define HEATER_1_MAXTEMP 275
#define HEATER_2_MAXTEMP 275
#define BED_MAXTEMP 150
#define PIDTEMP
#define BANG_MAX 255 // limits current to nozzle while in bang-bang mode; 255=full current
#define PID_MAX 255 // limits current to nozzle while PID is active (see PID_FUNCTIONAL_RANGE below); 255=full current
  #define PID_FUNCTIONAL_RANGE 10 // If the temperature difference between the target temperature and the actual temperature
  #define PID_INTEGRAL_DRIVE_MAX 255  //limit for the integral term
  #define K1 0.95 //smoothing factor within the PID
  #define PID_dT ((OVERSAMPLENR * 8.0)/(F_CPU / 64.0 / 256.0)) //sampling period of the temperature routine
    #define  DEFAULT_Kp 61.27
    #define  DEFAULT_Ki 1.78
    #define  DEFAULT_Kd 524.51
#define LYMAN_EXTRUDER
#define FILAMENT_SENSOR
#define DEFAULT_EXTRUDER_RPM 7 //define default extruder RPM
#define EXTRUDER_RPM_MAX FR3D_SERIAL_RPM_MAX
#define EXTRUDER_RPM_MIN 0.5
#define DEFAULT_PULLER_FEEDRATE 12.0 //default puller feedrate when turned on
#define PULLER_RPM_MIN 2.0 // min feedrate in manual control, 1 mm/sec min feed - limited by max pulse rate of 50,000
#define PULLER_RPM_MAX 80.0  // max feedrate in manual control 15mm/sec max feed - limited by max pulse rate of 50,000
#define DEFAULT_PULLER_WHEEL_CIRC 37.70 // default circumference of puller wheel in mm.
#define DEFAULT_SENSOR_RUNOUT_MIN 1 // default sensor runout min
#define DEFAULT_SENSOR_RUNOUT_MAX 5 // default sensor runout max
#define DEFAULT_WINDER_RPM_FACTOR 100  //factor for converting winder PW to rpm - reflects rpm of motor at 12v
#define DEFAULT_WINDER_SPEED 0  //default winder speed (0-DEFAULT_WINDER_RPM_FACTOR)
#define DEFAULT_INJECTION_TIME 5 //default injection time in seconds
#define DESIRED_FILAMENT_DIA 4.0 //define the default desired Filament diameter
#define PREHEAT_EXTRUDER_TEMP 150
#define  DEFAULT_fwidthKp 22.000 // 0.005 with hall sensor, 35.00 with optical sensor
#define  DEFAULT_fwidthKi 0.009 // 0.002 with hall sensor, 0.008 with optical sensor
#define  DEFAULT_fwidthKd 0.009 // 0.098 with hall sensor, 0.008 with optical sensor
#define  DEFAULT_fFact1 16300
#define  DEFAULT_fFact2 9.5
#define FR3D_HALL_DIAMETER_ENABLE_DEFAULT 1
#define FR3D_HALL_CAL_N 6
#define FR3D_HALL_CAL_MASK_ALL 0x3Fu
#define FR3D_HALL_CAL_ADC_DEFAULT_0 500.0f
#define FR3D_HALL_CAL_ADC_DEFAULT_1 508.0f
#define FR3D_HALL_CAL_ADC_DEFAULT_2 516.0f
#define FR3D_HALL_CAL_ADC_DEFAULT_3 524.0f
#define FR3D_HALL_CAL_ADC_DEFAULT_4 532.0f
#define FR3D_HALL_CAL_ADC_DEFAULT_5 540.0f
#define FR3D_HALL_DIAM_OFFSET_MM_DEFAULT 0.0f
#define FR3D_HALL_PATTERN_SIX 6
#define FR3D_HALL_CAL_VALID_DEFAULT 0
#define FR3D_HALL_PAT_MM_0 1.50f
#define FR3D_HALL_PAT_MM_1 1.60f
#define FR3D_HALL_PAT_MM_2 1.70f
#define FR3D_HALL_PAT_MM_3 1.80f
#define FR3D_HALL_PAT_MM_4 1.90f
#define FR3D_HALL_PAT_MM_5 2.00f
#define FR3D_PRED_ENABLE_DEFAULT 1         // predictor enabled
#define FR3D_PRED_MODE_DEFAULT 0           // 0=manual suggest, 1=automatic apply
#define FR3D_PRED_WINDOW_SIZE_DEFAULT 3
#define FR3D_PRED_TARGET_DIAM_MM_DEFAULT 1.75f
#define FR3D_MANUAL_DIAM_ASSUME_TARGET_MS 70000UL
#define FR3D_PRED_DEADBAND_HALF_MM_DEFAULT 0.035f
#define FR3D_PRED_TEMP_MATCH_MAX_C_DEFAULT 2.0f
#define FR3D_PRED_R_MIN_DEFAULT 14.0f
#define FR3D_PRED_R_MAX_DEFAULT 26.0f
#define FR3D_PRED_T_MIN_DEFAULT 173
#define FR3D_PRED_T_MAX_DEFAULT 182
#define FR3D_PRED_DELTA_R_MIN_DEFAULT 0.030f
#define FR3D_PRED_DELTA_R_MAX_DEFAULT 0.500f
#define FR3D_PRED_K_SPAN_R_DEFAULT 8.0f
#define FR3D_PRED_K_ERR_R_DEFAULT 18.0f
#define FR3D_PRED_DELTA_T_MIN_DEFAULT 0.20f
#define FR3D_PRED_DELTA_T_MAX_DEFAULT 1
#define FR3D_PRED_K_SPAN_T_DEFAULT 15.0f
#define FR3D_PRED_K_ERR_T_DEFAULT 55.0f
#define FR3D_PRED_R_SWITCH_MARGIN_DEFAULT 2.0f
#define FR3D_PRED_T_SWITCH_MARGIN_DEFAULT 2
#define FR3D_PRED_T_SETTLE_FUSIONS_MIN 15
#define FR3D_PRED_T_SETTLE_FUSIONS_MAX 20
#define FR3D_PRED_T_SETTLE_FUSIONS_DEFAULT FR3D_PRED_T_SETTLE_FUSIONS_MIN
#define FR3D_PRED_HOLD_M_DEFAULT 0.50f
#define FR3D_PRED_HOLD_TIMEOUT_S_DEFAULT 60
#define FR3D_PRED_EP_DE_SIG 2.0f
#define FR3D_PRED_EP_DP_FLAT 2.0f
#define FR3D_PRED_EP_PERSIST_MS 90000UL
#define FR3D_PRED_REGIME_MS 40000UL
#define FR3D_PRED_OPT_FREEZE_MS 90000UL
#define FR3D_PRED_OPT_DWELL_MS 90000UL
#define FR3D_PRED_EP_CORRECT_E 0.50f
#define FR3D_PRED_P_BAND 5.0f
#define FR3D_PRED_P_ABS_MIN 5.0f
#define FR3D_PRED_P_ABS_MAX 45.0f
#define FR3D_PRED_OPT_E_STEP 0.25f
#define FR3D_PRED_P_STAR_EPS 1.0f
#define FR3D_PRED_OPT_BAND_SLACK_MM 0.020f
#define FR3D_PRED_F_MIN_PCT 30
#define FR3D_PRED_F_MAX_PCT 100
#define FR3D_PRED_OPT_ABORT_DIAM_STREAK 2
#define FR3D_CSV_CYCLE_S_DEFAULT 2
#define FR3D_CSV_CYCLE_S_MIN 2
#define FR3D_CSV_CYCLE_S_MAX 2
#define FR3D_DIAM_JUMP_DEBOUNCE_MM_DEFAULT 0.100f
#define FR3D_DIAM_PENDING_MATCH_MM_DEFAULT 0.030f
#define FR3D_DIAM_DEBUG_DEFAULT 0
#define PULLER_PID_INTEGRATOR_WIND_LIMIT 1000000 //absolute value of integrator windup max value
#define FAN_ACTIVE_TEMP 135
#define FAN_INACTIVE_TEMP 125
#define DEFAULT_LENGTH_CUTOFF 250000  //length in mm where extruder will shut down
#define EXTRUDE_MINTEMP 148  //min temp that extruder motor will run
#define PREVENT_DANGEROUS_EXTRUDE
#define DEFAULT_ESTEP_PER_REV 489.6  //default setting for the extruder step calibration  1:15.3 gear. 61.6=1/2, 122.8=1/4, 244.8=1/6, 489.6=1/8
#define DEFAULT_PSTEP_PER_MM 10.61  //default setting for the puller motor step calibration  without gear
#define DEFAULT_AXIS_STEPS_PER_UNIT   {78.7402,78.7402,200.0*8/3,DEFAULT_ESTEP_PER_REV, DEFAULT_PSTEP_PER_MM}
#define DEFAULT_MAX_FEEDRATE          {500, 500, 5, 50, 50}    // (mm/sec)
#define DEFAULT_MOTOR_ACCELERATION  300   // E and P max acceleration in mm/s^2 - controls extruder acceleration
#define DEFAULT_EJERK                 1.0    // (mm/sec)
#define DEFAULT_PJERK				  1.0	// (mm/sec)
#define MAX_BED_POWER 255 // limits duty cycle to bed; 255=full current
#define PREVENT_LENGTHY_EXTRUDE
#define EXTRUDE_MAXLENGTH (X_MAX_LENGTH+Y_MAX_LENGTH) //prevent extrusion of very large distances.
#define THERMAL_RUNAWAY_PROTECTION_PERIOD 180 //in seconds
#define THERMAL_RUNAWAY_PROTECTION_HYSTERESIS 20 // in degree Celsius
#define THERMAL_RUNAWAY_PROTECTION_BED_PERIOD 20 //in seconds
#define THERMAL_RUNAWAY_PROTECTION_BED_HYSTERESIS 5 // in degree Celsius
#define ENDSTOPPULLUPS // Comment this out (using // at the start of the line) to disable the endstop pullup resistors
  #define ENDSTOPPULLUP_XMAX
  #define ENDSTOPPULLUP_YMAX
  #define ENDSTOPPULLUP_ZMAX
  #define ENDSTOPPULLUP_XMIN
  #define ENDSTOPPULLUP_YMIN
  #define ENDSTOPPULLUP_ZMIN
const bool X_MIN_ENDSTOP_INVERTING = true; // set to true to invert the logic of the endstop.
const bool Y_MIN_ENDSTOP_INVERTING = true; // set to true to invert the logic of the endstop.
const bool Z_MIN_ENDSTOP_INVERTING = true; // set to true to invert the logic of the endstop.
const bool X_MAX_ENDSTOP_INVERTING = true; // set to true to invert the logic of the endstop.
const bool Y_MAX_ENDSTOP_INVERTING = true; // set to true to invert the logic of the endstop.
const bool Z_MAX_ENDSTOP_INVERTING = true; // set to true to invert the logic of the endstop.
#if defined(COREXY) && !defined(DISABLE_MAX_ENDSTOPS)
  #define DISABLE_MAX_ENDSTOPS
#endif
#define X_ENABLE_ON 0
#define Y_ENABLE_ON 0
#define Z_ENABLE_ON 0
#define E_ENABLE_ON 0 // For all extruders
#define P_ENABLE_ON 0 //FMM for P_AXIS
#define DISABLE_X false
#define DISABLE_Y false
#define DISABLE_Z false
#define DISABLE_E false // For all extruders
#define DISABLE_P false //FMM for P_AXIS
#define INVERT_X_DIR true    // for Mendel set to false, for Orca set to true
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

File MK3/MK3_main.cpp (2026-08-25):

/* -*- c++ -*- */

/*
 MACKEREL - Filament Extruder firmware based on Marlin for repraps.
 Copyright (C) 2014 Filip Mulier/Hugh Lyman

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
 ---------------------------------------------------------------------------
 Modified by FR3D Addon — Claudio Dadone — 14 Jul 2026

 This firmware incorporates diameter measurement and predictive diameter
 control (manual / automatic modes).

 Prepared for optional remote control via Raspberry Pi Zero 2 W gateway
 and web app (MK3s + FR3D Addon). That host/app stack is not published
 in this firmware repository.

 For more information: http://fr3d-addon.web.app/
 ---------------------------------------------------------------------------
 */

/*
 This firmware was designed in conjunction with Hugh Lyman to control a Lyman filament extruder
 with geared stepper motors. It is currently designed to support the RAMPS 1.4 with Smart LCD 2004
 and depends on a prototype filament width sensor. It replaces much of the control electronics in
 the current design with one controller. It can control the extruder motor, puller motor, Extruder
 heater (PID) with thermistor, winder motor, filament cooling fan and has input for a filament width
 sensor. The processes and menus have been adapted to control a filament extruder. 
 
 This firmware is based on Marlin 3D Printer Firmware but also has many original parts.
  (https://github.com/ErikZalm/Marlin)
 
 Marlins eat Mackerels, 3D printers eat filament. 

 */

#include "MK3.h"

#ifdef ENABLE_AUTO_BED_LEVELING
#include "vector_3.h"
  #ifdef AUTO_BED_LEVELING_GRID
    #include "qr_solve.h"
  #endif
#endif // ENABLE_AUTO_BED_LEVELING

#include "ultralcd.h"
#include "planner.h"
#include "stepper.h"
#include "temperature.h"
#include "motion_control.h"
#include "cardreader.h"
#include "watchdog.h"
#include "ConfigurationStore.h"
#include "fr3d_telemetry.h"
#include "fr3d_gateway_id.h"
#include "language.h"
#include "pins_arduino.h"
#include "math.h"
#include <Arduino.h>

#ifdef BLINKM
#include "BlinkM.h"
#include "Wire.h"
#endif

#if NUM_SERVOS > 0
#include "Servo.h"
#endif

#if defined(DIGIPOTSS_PIN) && DIGIPOTSS_PIN > -1
#include <SPI.h>
#endif

#define VERSION_STRING  "1.1.0"
#define FR3D_MK3_FW_DATE "2026-04-27"

// look here for descriptions of G-codes: http://linuxcnc.org/handbook/gcode/g-code.html
// http://objects.reprap.org/wiki/Mendel_User_Manual:_RepRapGCodes

//Implemented Codes
//-------------------
// G0  -> G1
// G1  - Coordinated Movement X Y Z E
// G2  - CW ARC
// G3  - CCW ARC
// G4  - Dwell S<seconds> or P<milliseconds>
// G10 - retract filament according to settings of M207
// G11 - retract recover filament according to settings of M208
// G28 - Home all Axis
// G29 - Detailed Z-Probe, probes the bed at 3 or more points.  Will fail if you haven't homed yet.
// G30 - Single Z Probe, probes bed at current XY location.
// G90 - Use Absolute Coordinates
// G91 - Use Relative Coordinates
// G92 - Set current position to coordinates given

// M Codes
// M0   - Unconditional stop - Wait for user to press a button on the LCD (Only if ULTRA_LCD is enabled)
// M1   - Same as M0
// M17  - Enable/Power all stepper motors
// M18  - Disable all stepper motors; same as M84
// M20  - List SD card
// M21  - Init SD card
// M22  - Release SD card
// M23  - Select SD file (M23 filename.g)
// M24  - Start/resume SD print
// M25  - Pause SD print
// M26  - Set SD position in bytes (M26 S12345)
// M27  - Report SD print status
// M28  - Start SD write (M28 filename.g)
// M29  - Stop SD write
// M30  - Delete file from SD (M30 filename.g)
// M31  - Output time since last M109 or SD card start to serial
// M32  - Select file and start SD print (Can be used _while_ printing from SD card files):
//        syntax "M32 /path/filename#", or "M32 S<startpos bytes> !filename#"
//        Call gcode file : "M32 P !filename#" and return to caller file after finishing (similar to #include).
//        The '#' is necessary when calling from within sd files, as it stops buffer prereading
// M42  - Change pin status via gcode Use M42 Px Sy to set pin x to value y, when omitting Px the onboard led will be used.
// M80  - Turn on Power Supply
// M81  - Turn off Power Supply
// M82  - Set E codes absolute (default)
// M83  - Set E codes relative while in Absolute Coordinates (G90) mode
// M84  - Disable steppers until next move,
//        or use S<seconds> to specify an inactivity timeout, after which the steppers will be disabled.  S0 to disable the timeout.
// M85  - Set inactivity shutdown timer with parameter S<seconds>. To disable set zero (default)
// M92  - Set axis_steps_per_unit - same syntax as G92
// M104 - Set extruder target temp
// M105 - Read current temp
// M106 - Fan on
// M107 - Fan off
// M109 - Sxxx Wait for extruder current temp to reach target temp. Waits only when heating
//        Rxxx Wait for extruder current temp to reach target temp. Waits when heating and cooling
// M114 - Output current position to serial port
// M115 - Capabilities string
// M117 - display message
// M119 - Output Endstop status to serial port
// M126 - Solenoid Air Valve Open (BariCUDA support by jmil)
// M127 - Solenoid Air Valve Closed (BariCUDA vent to atmospheric pressure by jmil)
// M128 - EtoP Open (BariCUDA EtoP = electricity to air pressure transducer by jmil)
// M129 - EtoP Closed (BariCUDA EtoP = electricity to air pressure transducer by jmil)
// M140 - Set bed target temp
// M150 - Set BlinkM Color Output R: Red<0-255> U(!): Green<0-255> B: Blue<0-255> over i2c, G for green does not work.
// M190 - Sxxx Wait for bed current temp to reach target temp. Waits only when heating
//        Rxxx Wait for bed current temp to reach target temp. Waits when heating and cooling
// M200 D<millimeters>- set filament diameter and set E axis units to cubic millimeters (use S0 to set back to millimeters).
// M201 - Set max acceleration in units/s^2 for print moves (M201 X1000 Y1000)
// M202 - Set max acceleration in units/s^2 for travel moves (M202 X1000 Y1000) Unused in Marlin!!
// M203 - Set maximum feedrate that your machine can sustain (M203 X200 Y200 Z300 E10000) in mm/sec
// M204 - Set default acceleration: S normal moves T filament only moves (M204 S3000 T7000) in mm/sec^2  also sets minimum segment time in ms (B20000) to prevent buffer under-runs and M20 minimum feedrate
// M205 -  advanced settings:  minimum travel speed S=while printing T=travel only,  B=minimum segment time X= maximum xy jerk, Z=maximum Z jerk, E=maximum E jerk
// M206 - set additional homing offset
// M207 - set retract length S[positive mm] F[feedrate mm/min] Z[additional zlift/hop], stays in mm regardless of M200 setting
// M208 - set recover=unretract length S[positive mm surplus to the M207 S*] F[feedrate mm/sec]
// M209 - S<1=true/0=false> enable automatic retract detect if the slicer did not support G10/11: every normal extrude-only move will be classified as retract depending on the direction.
// M218 - set hotend offset (in mm): T<extruder_number> X<offset_on_X> Y<offset_on_Y>
// M220 S<factor in percent>- set speed factor override percentage
// M221 S<factor in percent>- set extrude factor override percentage
// M226 P<pin number> S<pin state>- Wait until the specified pin reaches the state required
// M240 - Trigger a camera to take a photograph
// M250 - Set LCD contrast C<contrast value> (value 0..63)
// M280 - set servo position absolute. P: servo index, S: angle or microseconds
// M300 - Play beep sound S<frequency Hz> P<duration ms>
// M301 - Set PID parameters P I and D
// M302 - Allow cold extrudes, or set the minimum extrude S<temperature>.
// M303 - PID relay autotune S<temperature> sets the target temperature. (default target temperature = 150C)
// M304 - Set bed PID parameters P I and D
// M400 - Finish all moves
// M401 - Lower z-probe if present
// M402 - Raise z-probe if present
// M500 - stores parameters in EEPROM
// M501 - reads parameters from EEPROM (if you need reset them after you changed them temporarily).
// M502 - reverts to the default "factory settings".  You still need to store them in EEPROM afterwards if you want to.
// M503 - print the current settings (from memory not from EEPROM)
// M540 - Use S[0|1] to enable or disable the stop SD card print on endstop hit (requires ABORT_ON_ENDSTOP_HIT_FEATURE_ENABLED)
// M600 - Pause for filament change X[pos] Y[pos] Z[relative lift] E[initial retract] L[later retract distance for removal]
// M665 - set delta configurations
// M666 - set delta endstop adjustment
// M605 - Set dual x-carriage movement mode: S<mode> [ X<duplication x-offset> R<duplication temp offset> ]
// M700 - Extruder data dump 
// M907 - Set digital trimpot motor current using axis codes.
// M908 - Control digital trimpot directly.
// M350 - Set microstepping mode.
// M351 - Toggle MS1 MS2 pins directly.
// M928 - Start SD logging (M928 filename.g) - ended by M29
// M999 - Restart after being stopped by error

//Stepper Movement Variables

//===========================================================================
//=============================imported variables============================
//===========================================================================


//===========================================================================
//=============================public variables=============================
//===========================================================================
#ifdef SDSUPPORT
CardReader card;
#endif
float homing_feedrate[] = HOMING_FEEDRATE;
bool axis_relative_modes[] = AXIS_RELATIVE_MODES;
unsigned char extrude_status =0;
float filament_width_desired= DESIRED_FILAMENT_DIA; //holds the desired filament width (i.e like 2.6mm)
int feedmultiply; //100->1 200->2
int saved_feedmultiply;

int extrudemultiply=100; //100->1 200->2
float extruder_feedrate;  //extruder real time 'feed rate' - yet we are really interested in RPM
float extruder_rpm; //real time extruder rpm
float extruder_rpm_set= DEFAULT_EXTRUDER_RPM; //setpoint for extruder RPM
float puller_feedrate_default = DEFAULT_PULLER_FEEDRATE; //puller motor feed rate in mm/sec
float puller_feedrate= DEFAULT_PULLER_FEEDRATE; //puller motor feed rate in mm/sec
float puller_feedrate_last = DEFAULT_PULLER_FEEDRATE;
float sum_measured_filament_width=0;  //numerator in average
float n_measured_filament_width=0;  //denominator in average
float avg_measured_filament_width=0; //average
float max_measured_filament_width=0; // max measured filament width 
float min_measured_filament_width=0; // min measured filament width 
float extrude_length=0; //length extruded
float fil_length_cutoff= DEFAULT_LENGTH_CUTOFF; //length of filament at which extruder shuts down
int default_winder_speed = DEFAULT_WINDER_SPEED;
int injectionTimeSeconds = DEFAULT_INJECTION_TIME;
unsigned long injectionModeStartMillis = -1;
int winder_rpm_factor = DEFAULT_WINDER_RPM_FACTOR;
uint8_t sinfin_compression_mode = DEFAULT_SINFIN_COMPRESSION;
#ifdef FR3D_SERIAL_HOST_DISABLE_GM
bool fr3d_serial_filter_msgs = DEFAULT_FR3D_SERIAL_FILTER_MSGS_ON;
#ifndef FR3D_SERIAL_HOST_ONLY_COMPACT
  /* 1: por USB solo acepta comandos compactos FR3D.
     0: bloquea solo G/M (comportamiento anterior). */
  #define FR3D_SERIAL_HOST_ONLY_COMPACT 1
#endif
#endif
unsigned long starttime=0;
unsigned long stoptime=0;

unsigned long duration=0;
unsigned long timeremaining=DEFAULT_LENGTH_CUTOFF/DEFAULT_PULLER_FEEDRATE*1000;  //used to hold a calculated time remaining in ms to hit fil length cutoff

int maxBeepSequenceLength = 20;
int beepSequence[20];
int currentBeepSequenceIndex = -1;
int currentBeepSequenceLength;
unsigned long currentBeepMillis;

void setBeepSequence(int bs[], int length)
{
  if (length > maxBeepSequenceLength)
    length = maxBeepSequenceLength;
  for (int i = 0; i < length; i++)
    beepSequence[i] = bs[i];

  currentBeepSequenceLength = length;
  currentBeepSequenceIndex = 0;
  currentBeepMillis = millis();

  WRITE(BEEPER,HIGH);

}

void beepSequenceLoop() {

  if (currentBeepSequenceIndex >= 0 && currentBeepSequenceIndex < currentBeepSequenceLength) {

    unsigned long elapsedMillis = millis() - currentBeepMillis;

    if (elapsedMillis > beepSequence[currentBeepSequenceIndex]) {
      currentBeepSequenceIndex++;
      currentBeepMillis = millis();
      if (currentBeepSequenceIndex % 2 == 0) {
        WRITE(BEEPER,HIGH);
      } else {
        WRITE(BEEPER,LOW);
      }
      if (currentBeepSequenceIndex >= currentBeepSequenceLength) {
        currentBeepSequenceIndex = -1;
        WRITE(BEEPER,LOW);
      }
    }
  }


}


float model_out;  //Smith predictor model out
float model_gain; //Smith predictor model gain
float model_param; //Smith Predictor low pass param
float smith_filter_out;
float smith_filter_param;

int model_delay[100]; //Smith predictor delay line 
float last_p_position=0.0;  //keeps track of last position updated in the delay line

float filament_control=0.0;
unsigned long runoutStartTimeMS = 0;
unsigned long safetycooldownStartTimeMS = 0;

int extruder_multiply[EXTRUDERS] = {100
  #if EXTRUDERS > 1
    , 100
    #if EXTRUDERS > 2
      , 100
    #endif
  #endif
};
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
void loop()
{

  encoderClicked = false;
  encoderLongPressed = false;

  unsigned long encoderMillis = millis();

  if (lcd_clicked()) {
    if (encoderDownTime == -1) {
      encoderDownTime = encoderMillis;
    }

    if (encoderMillis - encoderDownTime > 2000) {
      encoderLongPressed = true;
    }

  } else {
    if (encoderDownTime != -1) {
      if (millis() - encoderDownTime < 1000) {
        encoderClicked = true;
      } 
      encoderDownTime = -1;
    }
  }


  beepSequenceLoop();  

  if(buflen < (BUFSIZE-1))
    get_command();
  #ifdef SDSUPPORT
  card.checkautostart(false);
  #endif
  if(buflen)
  {
    #ifdef SDSUPPORT
      if(card.saving)
      {
        if(strstr_P(cmdbuffer[bufindr], PSTR("M29")) == NULL)
        {
          card.write_command(cmdbuffer[bufindr]);
          if(card.logging)
          {
            process_commands();
          }
          else
          {
            SERIAL_PROTOCOLLNPGM(MSG_OK);
          }
        }
        else
        {
          card.closefile();
          SERIAL_PROTOCOLLNPGM(MSG_FILE_SAVED);
        }
      }
      else
      {
        process_commands();
      }
    #else
      process_commands();
    #endif //SDSUPPORT
    buflen = (buflen-1);
    bufindr = (bufindr + 1)%BUFSIZE;
  }
  //check heater every n milliseconds
  manage_heater();
  manage_inactivity();
  checkHitEndstops();
  fr3d_diam_poll_samples();
  lcd_update(encoderClicked, encoderLongPressed);

  fr3d_csv_telemetry_poll();

  //FMM calculate max, min, and average filament width

  timebuff=millis();
  deltatime = timebuff-lasttime;  //calculate delta times
  lasttime = timebuff;  //keep track of last sample time
  

  if(extrude_length < fil_length_cutoff)
	  winderSpeed = default_winder_speed*255/winder_rpm_factor;  //keep winder on all the time unless at end of spool
  

  
  
  
  if((extrude_status & (ES_STATS_SET))  == (ES_STATS_SET) ) //check whether we should collect stats on filament width
	  {
	  
	  sum_measured_filament_width = sum_measured_filament_width+current_filwidth;
	  n_measured_filament_width = n_measured_filament_width + 1.0;
	  avg_measured_filament_width=sum_measured_filament_width/n_measured_filament_width;
	  max_measured_filament_width=max(max_measured_filament_width,current_filwidth);
	  if(round(min_measured_filament_width)==0)
		min_measured_filament_width=current_filwidth;
	  min_measured_filament_width=min(min_measured_filament_width,current_filwidth);
	  extrude_length=extrude_length+puller_increment;
	  

	  if(extrude_length >= fil_length_cutoff){  //check whether we extruded enough filament
		  setTargetHotend0(0);
		  winderSpeed = 0;
		  digitalWrite(CONTROLLERFAN_PIN, 0);  //stop Fan
		  extrude_status= extrude_status & ES_ENABLE_CLEAR;  //update extrude_status to shut down extruder
		  extrude_status= extrude_status & ES_STATS_CLEAR;  //shut down statistics
		  timeremaining=0;
		  LCD_MESSAGEPGM(MSG_EXTRUDE_COMPLETE);
      int beepSequence[5] = {1000, 500, 1000, 500, 1000};
      setBeepSequence(beepSequence, 5);

	  } else {
		  
		  if(puller_feedrate>0)
		  timeremaining = (fil_length_cutoff-extrude_length)/puller_feedrate*1000;
		  
	  }
		  
	  }
	// puller stop when filament stuck for more than 30 secs
  if  ((extrude_status & ES_AUTO_SET) > 0 && !(extrude_length >= fil_length_cutoff)) {
    
    if (current_filwidth < sensorRunoutMin || current_filwidth > sensorRunoutMax) {
      // MYSERIAL.println("sensor runout detected");
      if (runoutStartTimeMS == 0) {
        // MYSERIAL.println("starting timeout");
        runoutStartTimeMS = millis();
      }
    } else {
      runoutStartTimeMS = 0;
      // MYSERIAL.println("resetting timeout");
    }

    if (runoutStartTimeMS != 0) {
      unsigned long elapsedTimeMS = millis() - runoutStartTimeMS;
      // MYSERIAL.print("elapsed time: ");
      // MYSERIAL.println(elapsedTimeMS, DEC);
      if (elapsedTimeMS > 30000) {
        LCD_ALERTMESSAGEPGM(MSG_sensor_runout);
        int beepSequence[5] = {1000, 500, 1000, 500, 1000};
        setBeepSequence(beepSequence, 5);
        while(1)
        {
          disable_heater();
          disable_x();
          disable_y();
          disable_z();
          disable_e0();
          
          manage_heater();
          lcd_update(encoderClicked, encoderLongPressed);
          beepSequenceLoop();
        }
      }
    }
  } else {
    runoutStartTimeMS = 0;
    // MYSERIAL.println("not watching filwidth");
  }
    
// stop and cooldown when heated and extruder does not run for more than 20 minutes-safety cooldown
  if  ((extrude_status & ES_HOT_SET) > 0)  {
    
    if (extruder_rpm < 1) {
      // MYSERIAL.println("sensor runout detected");
      if (safetycooldownStartTimeMS == 0) {
        // MYSERIAL.println("starting timeout");
        safetycooldownStartTimeMS = millis();
      }
    } else {
      safetycooldownStartTimeMS = 0;
      // MYSERIAL.println("resetting timeout");
    }

    if (safetycooldownStartTimeMS != 0) {
      unsigned long elapsedTimeMS = millis() - safetycooldownStartTimeMS;
      // MYSERIAL.print("elapsed time: ");
      // MYSERIAL.println(elapsedTimeMS, DEC);
      if (elapsedTimeMS > 3000000) {
        LCD_ALERTMESSAGEPGM(MSG_SAFETY_COOLDOWN);
        int beepSequence[5] = {1000, 500, 1000, 500, 1000};
        setBeepSequence(beepSequence, 5);
        while(1)
        {
          disable_heater();
          disable_x();
          disable_y();
          disable_z();
          disable_e0();
          
          manage_heater();
          lcd_update(encoderClicked, encoderLongPressed);
          beepSequenceLoop();
        }
      }
    }
  } else {
    safetycooldownStartTimeMS = 0;
    // MYSERIAL.println("not watching filwidth");
  }

  float extruderTemp = degHotend(active_extruder);

  
  //FMM generate extruder motion based on LCD inputs
  #if defined(EXTRUDER_MOTOR_ON_OFF_PIN) && EXTRUDER_MOTOR_ON_OFF_PIN > -1
  if (READ(EXTRUDER_MOTOR_ON_OFF_PIN))  //check if pin is high (=off)
	  extrude_status=extrude_status & ES_SWITCH_CLEAR;
  else
	  extrude_status= extrude_status | ES_SWITCH_SET;
  #else
  extrude_status = extrude_status | ES_SWITCH_SET;  // sin interruptor físico: equivalente a "motor habilitado"
  #endif
  
  if(extruderTemp > EXTRUDE_MINTEMP)  //check if extruder at min heated temp
	  extrude_status=extrude_status | ES_HOT_SET;
  else
	  {
	  extrude_status=extrude_status & ES_HOT_CLEAR;
	  extrude_status=extrude_status & ES_TEMP_CLEAR;
	  }
 
  
 
  if (extruderTemp > FAN_ACTIVE_TEMP) {
    digitalWrite(CONTROLLERFAN2_PIN, 1);  //start Fan
  } else if (extruderTemp < FAN_INACTIVE_TEMP) {
    digitalWrite(CONTROLLERFAN2_PIN, 0);  //stop Fan
  }

		  
  if(((extruderTemp >= (degTargetHotend(active_extruder)-TEMP_WINDOW)) && (extruderTemp <= (degTargetHotend(active_extruder)+TEMP_WINDOW)))  && ((extrude_status & ES_TEMP_SET)==0))  //check if extruder at or near setpoint
  	  {
	  extrude_status=extrude_status | ES_TEMP_SET;
    int beepSequence[5] = {1000, 500, 1000, 500, 1000};
    setBeepSequence(beepSequence, 5);
	  LCD_MESSAGEPGM(MSG_HEATING_COMPLETE);
  	  }
  	
  if (extrude_status && ES_TEMP_SET > 0 && extrude_status && ES_ENABLE_CLEAR_NO_AUTO > 0 && encoderLongPressed && injectionModeStartMillis == -1) {
    injectionModeStartMillis = millis();
    puller_feedrate = 0;
	  extrude_status=extrude_status|ES_ENABLE_SET; 
    LCD_MESSAGEPGM(MSG_INJECTION_MODE);
  }

  if (injectionModeStartMillis != -1) {

    unsigned long elapsedTimeMS = millis() - injectionModeStartMillis;
    unsigned long injectionTimeMillis = (unsigned long) injectionTimeSeconds * 1000;
    if (elapsedTimeMS > injectionTimeMillis) {
      injectionModeStartMillis = -1;
      extrude_status=extrude_status & ES_ENABLE_CLEAR_NO_AUTO;
      LCD_MESSAGEPGM(MSG_HEATING_COMPLETE);
    }
  }
  
  if((extrude_status & ES_ENABLE_SET) >0){
	  
	  
	  
	  
	  
	 //old 
	 // feedrate=20*60;
	 // extruder_increment=feedmultiply/100.0;
	 // puller_increment=extruder_increment*pullermultiply/1000.0;
	  
	  //extruder_feedrate=feedrate*extruder_increment/60.0;
	  //puller_feedrate=extruder_feedrate*pullermultiply/1000.0;
	  
	 //new
	  extruder_increment=extruder_rpm_set/EXTRUDER_RPM_MAX*8;  //make extruder increment 1 unit for max RPM and scale down as RPM input decreases *8 for more duration (removes pulsing)
	  extruder_feedrate=extruder_rpm_set/0.6;
	  puller_increment=puller_feedrate*0.6/EXTRUDER_RPM_MAX*8;  //make puller increment vary to control it *8 for more duration (removes pulsing)
	  
	  
	  
	  
	  
	  //calculate move  - always scale step size to feedmultiply (was previously fix step side of 0.1)
	  destination[P_AXIS] = puller_increment + current_position[P_AXIS]; //puller
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

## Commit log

2026-07-14 Add original MK3 firmware (Mackerel base, without FR3D Addon)
    [Configuration.h, Configuration_adv.h]
2026-07-14 Add MK3 + FR3D Addon by Claudio Dadone
    [Configuration.h]
2026-07-14 docs: add MK3-FR3D-Addon.zip for Arduino IDE download
2026-07-21 Release Pattern Diameter presets and refresh standalone docs.
    Ship dual calibration presets with DOFF reset, updated ZIP/PDF, and INFIDEL printable parts.
    [Configuration.h, Hall_Sensor_Parts.stl]
2026-07-21 docs: refresh user guide PDF/DOCX with new Diameter Sensor LCD screens.
    Includes Pattern Diameter, CALIBRATE, and simulated Need Calibrate! figures.
2026-07-23 Release MK3 FR3D firmware: EEPROM V30, 2 s fusion, CSVQ, settle/hold.
    Refresh dist/MK3-FR3D-Addon.zip and docs for Arduino IDE download.
    [Configuration.h]
2026-07-31 fix: serial T max follows predictor Tmax+5
    Replace fixed 190 C USB temperature ceiling with max(190, pred Tmax+5), heater-safe. Refresh MK3 zip and document the control change.
    [Configuration.h]
2026-08-04 Release MK3 FR3D: predictor UI codes, DH always on, zip refresh.
    [Configuration.h]
2026-08-05 update MK3 Hall pattern B to 1.70/1.75/2.00 default
    [Configuration.h]
2026-08-14 Release DIAMSRC sensor modes (A3 / USB / Manual) and refresh MK3 ZIP.
    Ship exclusive diameter sources for LCD and host; update CHANGELOG for gateway-v2.4.1.
    [Configuration.h]
2026-08-15 Release Optimizar P* firmware and refresh MK3 ZIP, README, and changelog.
    [Configuration.h]
2026-08-17 Release 2.4.12: Manual Ø 1.20-2.80 mm, Apply Target D, firmware zip.
2026-08-18 Docs: ayuda web 2.0.34 ampliada (guía rápida, arquitectura, tips).
    CHANGELOG, README y export DOCX de revisión ES (106 temas). Gateway OTA sigue en gateway-v2.4.12.
2026-08-18 Docs: gateway OTA 2.4.13 (Pi zip para probar update desde Flutter).
2026-08-19 Release 2.4.15: Hall Analog A3 6-point (EEPROM V32), firmware zip and help 2.0.35.
    [Configuration.h]
2026-08-25 Manual Ø: firmware asume PREDTGT a 70 s (AR) y ayuda operativa.
    Actualiza MK3-FR3D-Addon.zip y docs/help_catalog.json (app 2.0.36).
    [Configuration.h]
2026-08-28 Document Pi 3B gateway and BDWidth sensor alongside Pi Zero 2 W.

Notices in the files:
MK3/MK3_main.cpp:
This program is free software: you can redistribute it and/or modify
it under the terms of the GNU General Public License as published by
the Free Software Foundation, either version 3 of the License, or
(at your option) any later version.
